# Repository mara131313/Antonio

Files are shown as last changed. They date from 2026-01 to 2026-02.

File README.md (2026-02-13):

# Antonio
Final project for "Introduction to Robotics" (2025–2026), focused on interactive robotics, audio-driven behavior, and custom human–robot interaction.  

Project by Andrei Cosmin Petru, Pincu Victor Andrei and Vraciu Mara Alina

## DESCRIPTION 
This project brings together two complementary builds into one cohesive system. There will be a robot moving on tank tracks and a touch screen remote that controls it.  

The robot is responsible for autonomous behavior, movement, and audio-visual feedback, while the remote provides an intuitive and playful human–robot interface.

### ABOUT ROBOT
The robot "ANTONIO" features a red panda–inspired designed for expressive and interactive behavior. ANTONIO will be equipped with a speaker capable of playing multiple music genres. For each music category, the robot will perform a specific “emote” by coordinating movements of its hands, head, tail, and “legs”, allowing it to dance according to the music.  

ANTONIO can move when the user interacts with a remote controller. If the user chooses to control the robot’s movement while it is dancing, they will have full control over its direction. Otherwise, ANTONIO will move autonomously based on the selected music genre.  

The remote includes an integrated microSD card on which music files can be downloaded and stored. Two music recognition methods are planned. The first method relies on manually assigned tags that define the genre of each song. The second method uses basic pattern recognition by analyzing drum rhythms, aiming to provide a lightweight and feasible genre classification approach. For this stage of our presentation, we implemented the first method.  
  
ANTONIO features two visual output elements:
- a face display used to show animated expressions
- a belly display that provides real-time audio visualization reacting to the rhythm and intensity of the music

#### 1. HANDS
  - wrists: 
    - up-down movement controlled by a servo motor and a gear mechanism
    - range is approximately 180°
  - shoulders: 
    - rotational movement driven by servo motors
    - range is up to 270°
2. HEAD:
  - neck: up-down movement controlled by a servo motor and a gear mechanism

3. TAIL: up-down movement controlled by a servo motor and a gear mechanism
  
4. LEGS: movement is achieved using tank tracks powered by DC motors
  - forward and backward motion : both tracks rotate at the same speed in the same direction
  - left and right turns: steering is performed using differential drive (one track moves while the other remains stationary)

### ABOUT REMOTE
The remote controller serves two main purposes: controlling the robot's movement and selecting various settings.  

The proposed design of the remote is inspired by a red panda paw, matching the robot’s red panda–inspired visual identity. This design was chosen to make the interaction playful, intuitive, and visually distinctive. At the center of the controller, a touch display will be integrated for menu navigation and visual feedback.  

An on/off power button will be placed on the tip of the pinky finger. The thumb fingertip will include a joystick used for controlling the robot's movement. Additionally, a buzzer will be integrated below the display, providing audio feedback when selecting or confirming menu options.  

1. MOVEMENT 
  - the robot's direction is controlled using a joystick located on the thumb
  - the joystick allows forward, backward, and left/right movement 
2. SETTINGS
  - remote settings:
    - theme song: allows turning the theme song on/off
    - volume: allows adjusting the volume of the buzzer
    - brightness: allows adjusting the brightness of the remote's display
  - music: allows selecting different tracks, skipping, pausing and selecting previous songs
  - robot settings:
    - face expression: allows changing ANTONIO's face from the established options
    - brightness: allows adjusting ANTONIO's 2 displays' brightness (*not yet*)
    - volume: allows adjusting ANTONIO'S spearks' volume (*not yet*)
    - speed: allows choosing the speed at which ANTONIO moves (*not yet*)
  - test mode: allows testing each moving component individually (*not yet*)
  - about creators: shows info about the creators of ANTONIO :
    - Vraciu Mara-Alina - https://github.com/mara131313
    - Andrei Cosmin Petru - https://github.com/cosmo1avo
    - Pincu Victor Andrei - https://github.com/PincuVictor  
    - each creator will have their own individual dance planned (*not yet*)

## BILL OF MATERIALS 
### ROBOT:
    - 4 x SG90 Servo motors
    - 2 x MG995 Servo motors
    - 2 x DC motors 125:1 Gear ratio
    - ESP32
    - Servo driver PCA9685
    - Charging module TP5100
    - Audio amplifier module PAM8403
    - 2 x Speaker 3W 4Ω
    - Microphone module
    - 2 x Samsung 18650 Li-ion 3.7V battery
    - Module slot card microSD
    - Module BMS Li-ion 2s 7.4V 20A
    - DC power jack adaptor
    - 2 x Voltage regulator buck converter LM2596
    - Dual H-bridge L298N
    - TFT/OLED display
    - OLED Display

### REMOTE:
    - Touch Display (NX4024K032_011)
    - ESP32 
    - 1 x Samsung 18650 Li-ion 3.7V battery
    - Charging module TP5100
    - Voltage regulator boost converter HW626
    - Buzzer
    - Capacitor
    - Joystick
    - Module BMS Li-ion 3.7V 20A
    - DC power jack adaptor

## Features
### ROBOT
- Audio-driven dancing behavior based on music genre
- Real-time audio playback from microSD card
- Music genre recognition system
- Expressive animated face display
- Real-time audio-reactive belly visualization
- Coordinated multi-servo movement (hands, head, tail)
- Differential drive tank-track locomotion
- Autonomous movement based on selected music genre
- Manual movement override via remote controller
- Modular and expandable hardware architecture

### REMOTE
- Touchscreen: multi-page menu system with smooth scrolling for the music library.
- Joystick-based movement control
- Audio Feedback: buzzer calibrated for musical frequencies and variable volume using PWM (Duty Cycle) mapping
- Visual feedback through touch display
- Wireless Communication: real-time transmission using the ESP-NOW protocol to ensure minimal latency

### SYSTEM
- Concurrent handling of motors, audio, and displays
- Real-time human–robot interaction

## QUESTIONS
### 1. What is the system boundary?
For the robot:
  - inside: ESP32, all motors, OLEDs, Audio (Speaker, Amp), Battery and physical chassis/tracks.
  - outside: the floor, obstacles and the bluetooth signal from the remote.

For the remote:
  - inside: ESP32, Touchscreen, joystick, push button and an internal battery.
  - outside: the user (human) and the bluetooth signal being sent to the robot.

### 2. Where does intelligence live?
Primary intelligence lives in the robot, which processes input from the remote and makes decisions related to movement, audio playback, and visual feedback.

### 3. What is the hardest technical problem?
The hardest technical problem will be system concurrency. Having a lot of motors, audio and updating the display  will make synchronization more difficult, therefore creating blocking problems if not handled properly. 

### 4. What is the minimum demo?

The minimum demo will be showing moving on tank tracks. The movement is controlled by the touchscreen remote. Ideally, in this prototype we will be able to play at least one track on the speaker and react to it.

### 5. Why is this not just a tutorial?
This is not just a tutorial because we are making our own designs for the robot's design and movement, our own interface for the remote, and our own unique interactions. This tutorial would have to include days worth of footage to cover the steps.

### 6. Do you need an ESP32?
 Yes, we will be needing 2 ESP32.

## ROUGH SKETCH
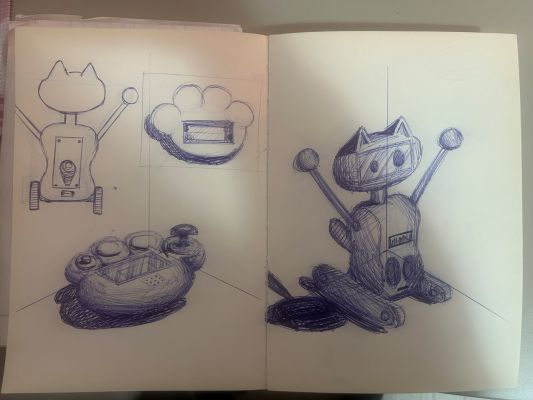
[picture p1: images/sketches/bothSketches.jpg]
Sketch


## IMPLEMENTATION DETAILS
This section outlines the realization of the project, transitioning from initial concepts to the fully functional physical prototype.

### 3D DESIGN & MODELING
The physical structure of both ANTONIO and the remote was modeled from scratch to adhere to the Red Panda aesthetic while ensuring mechanical robustness.
- **Robot Chassis, Arms, and Head:** Engineered to house dual Li-ion batteries, speakers, the visualizer screen, ESP32, H-bridge motor driver, breadboards, shift registers, amplifier, microphone, and DC motors (driving the master/slave wheels and tracks). The design integrates a charging module, BMS, voltage regulators, and a 3.5-inch display, while providing sturdy anchor points for the 6 servos controlling the arms, head, tail, and paws.
- **Locomotion System:** Custom-designed sprocket wheels and track links, 3D printed to ensure optimal grip and smooth differential steering.
- **Remote Casing:** Modeled as a stylized paw, prioritizing ergonomics for joystick manipulation and touchscreen visibility. The enclosure accommodates a Li-ion battery, ESP32, switch button, touchscreen (with stylus), charging module, BMS, buzzer, voltage regulator, and microSD card slot.
- **Lead Designer:** **Andrei Cosmin-Petru** is responsible for designing and modeling all custom 3D components for the project.

### REMOTE INTERFACE (GUI)
The remote serves as the command center, featuring a custom Graphical User Interface (GUI) tailored for the touch display.
- **Menu Structure:** Organized into intuitive pages (Test Mode, Settings, Music) with large, touch-friendly elements. It includes configuration settings for both ANTONIO and the remote, enabling customizations such as facial expressions, theme songs, brightness and description of the project's creators. The music tab features a scrollable list of 20 songs, displays random custom artwork for each track, and includes playback controls (pause/resume, next, previous).
- **User Feedback:** Provides immediate visual updates on the screen and audio cues via the integrated buzzer when commands are registered.
- **Data Transmission:** Encodes user inputs (drive vectors, volume states, emote requests) into optimized data packets sent wirelessly to the robot.
- **Lead Developer (Interface):** **Vraciu Mara Alina** is responsible for designing and implementing the custom, intuitive user interface, with each component across every page individually crafted and built from the ground up.

### FIRMWARE & CONTROL LOGIC
The "brain" of the robot is designed to handle high-concurrency requirements, ensuring that music playback remains uninterrupted while the robot dances or moves.
- **Dual-Core Architecture:** Leverages the ESP32's dual cores to separate blocking tasks (Audio decoding, WiFi/ESP-NOW communication on Core 0) from real-time operations (Motor control, Servo choreography, Display updates on Core 1).
- **Audio-Motion Synchronization:** Utilizes specific algorithms to translate music genres into distinct servo choreographies.
- **State Management:** Implements a robust state machine that seamlessly switches between "Autonomous Dance Mode" and "Manual Override" instantly upon detecting joystick input.
- **Lead Developer:** **Pincu Victor Andrei** is responsible for component selection and the electrical design strategy, ensuring optimal power distribution and operational safety. He also developed the hardware logic and communication between modules using FreeRTOS.

### ASSEMBLY & INTEGRATION
The final build focused on reliable power distribution and the compact integration of all components.
- **Power Management:** Integration of BMS modules and buck converters to supply stable, isolated voltage levels for the logic units (3.3V/5V) and high-torque motors (7.4V).
- **Wire Routing:** Strategic internal cable management to prevent interference with moving parts, particularly around the rotating shoulder and neck mechanisms.
- **Component Mounting:** Secure placement of the PCA9685 driver and L298N motor controller to ensure vibration resistance and effective heat dissipation.
- **Assembly Team:** All three creators are responsible for the physical assembly of the project, including soldering, surface finishing (sanding), component placement, and final system integration.

## DIAGRAMS
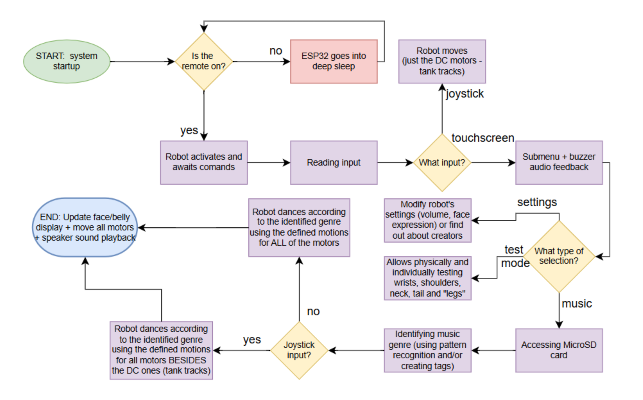
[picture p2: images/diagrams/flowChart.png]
SoftwareArchitecture


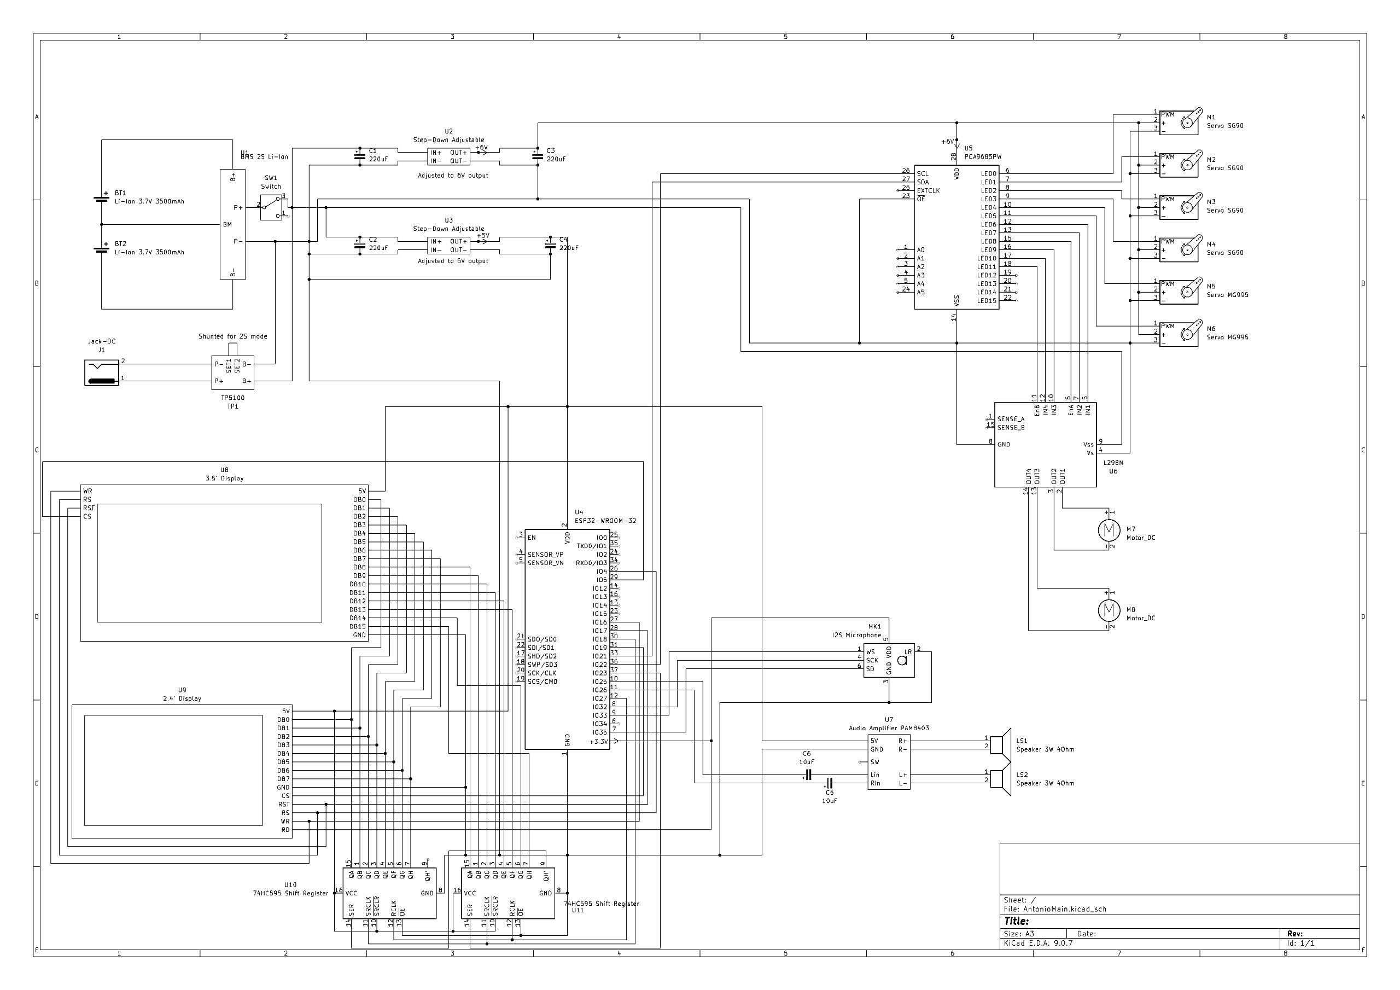
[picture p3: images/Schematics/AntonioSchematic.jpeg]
AntonioSchematic


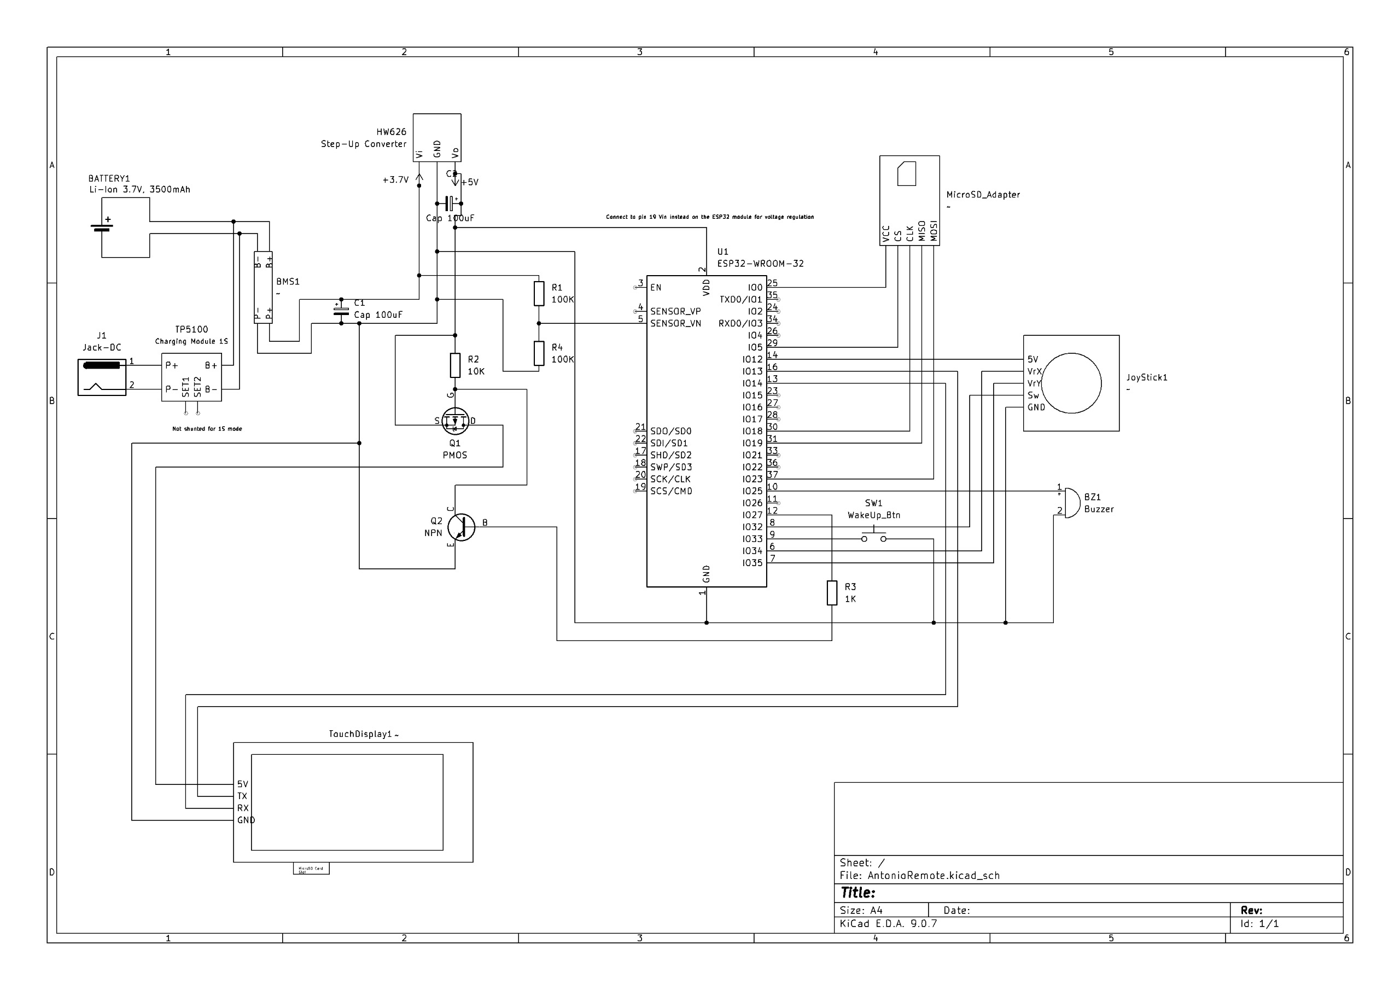
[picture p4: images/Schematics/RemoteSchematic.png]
RemoteChematic


- Link to the youtube video:
https://youtu.be/va7jiXDgWas

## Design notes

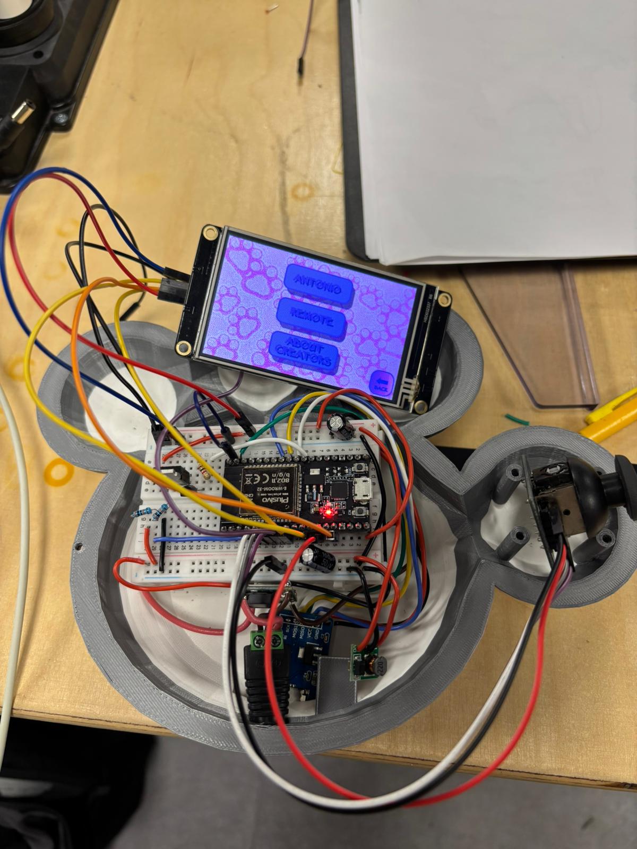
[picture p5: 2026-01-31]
images/ProgressPhotosRemote/Progress4.jpeg

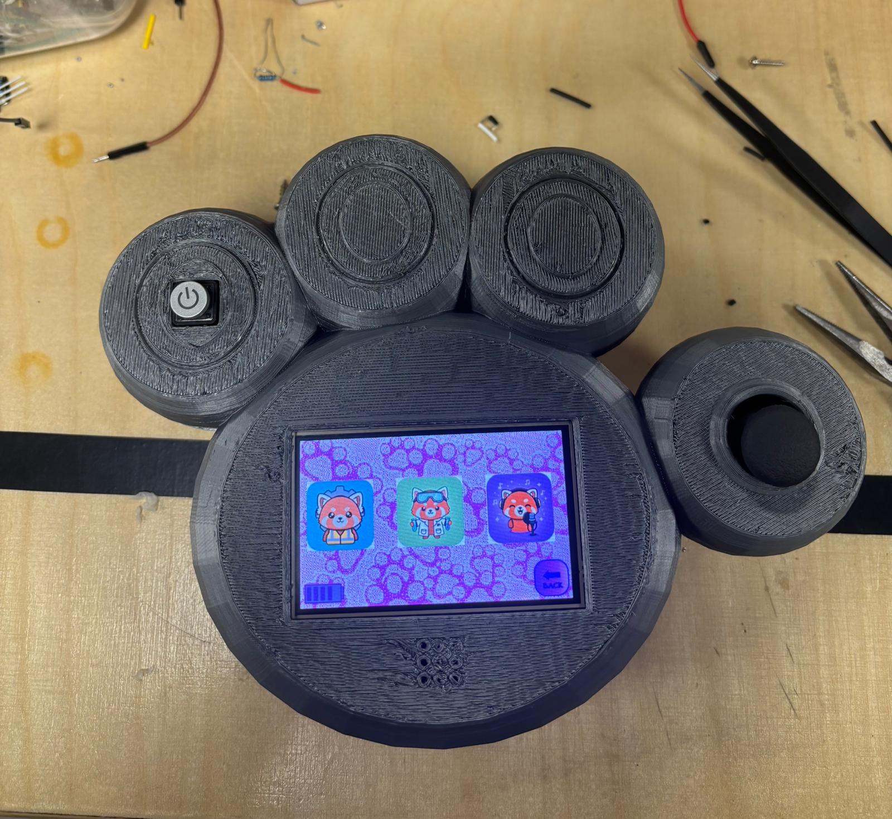
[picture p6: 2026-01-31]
images/ProgressPhotosRemote/Progress8.jpeg

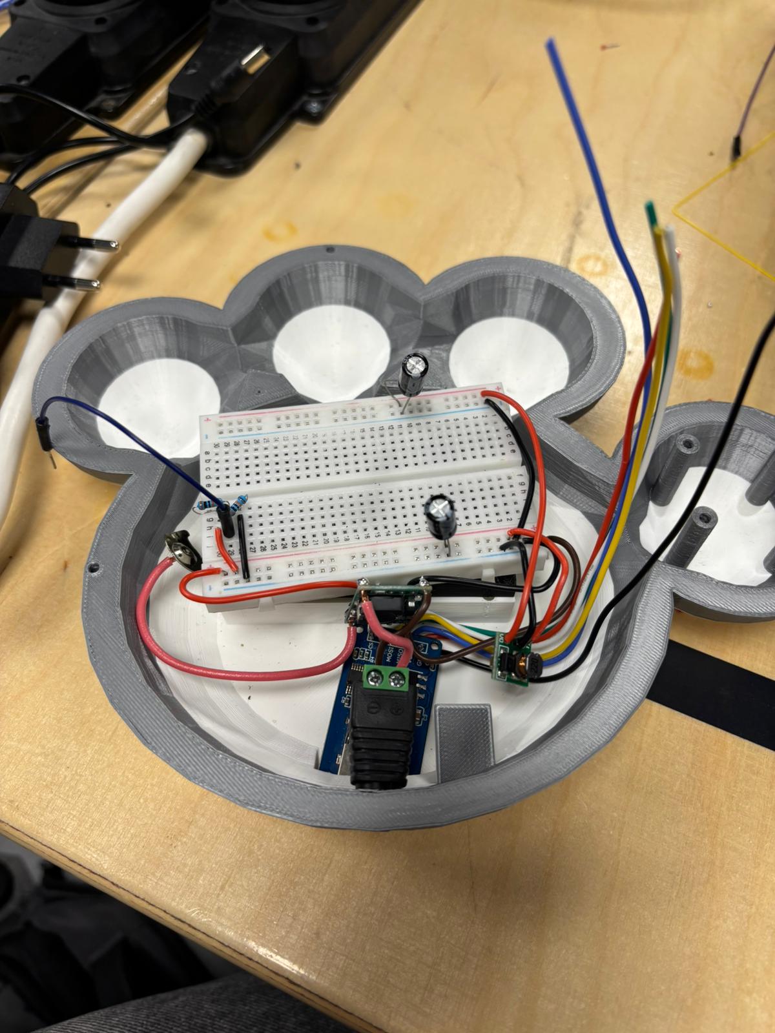
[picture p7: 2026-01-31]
images/ProgressPhotosRemote/Progress3.jpeg

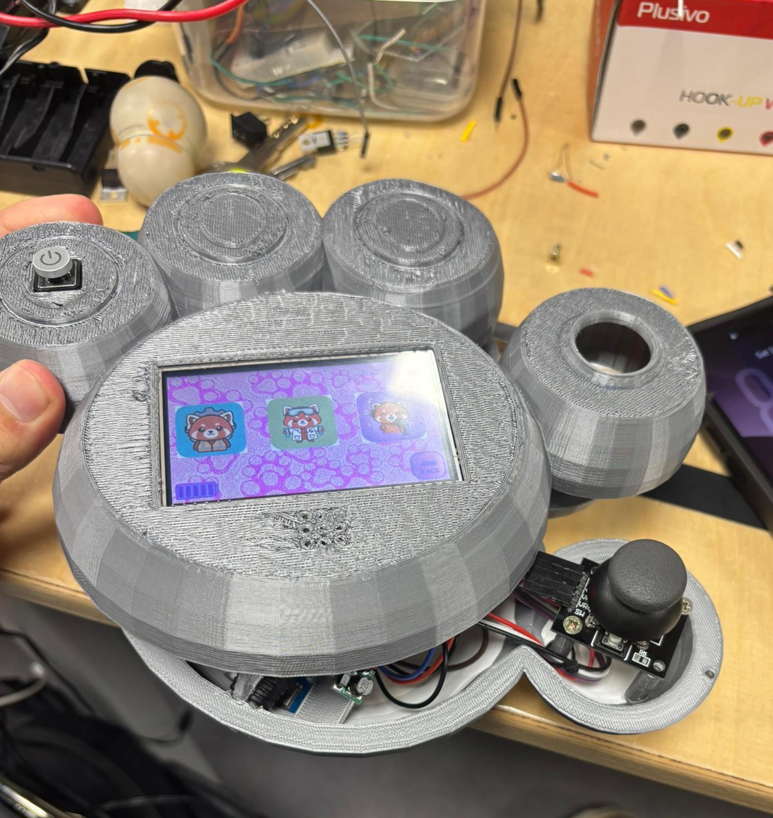
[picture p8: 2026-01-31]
images/ProgressPhotosRemote/Progress7.jpeg

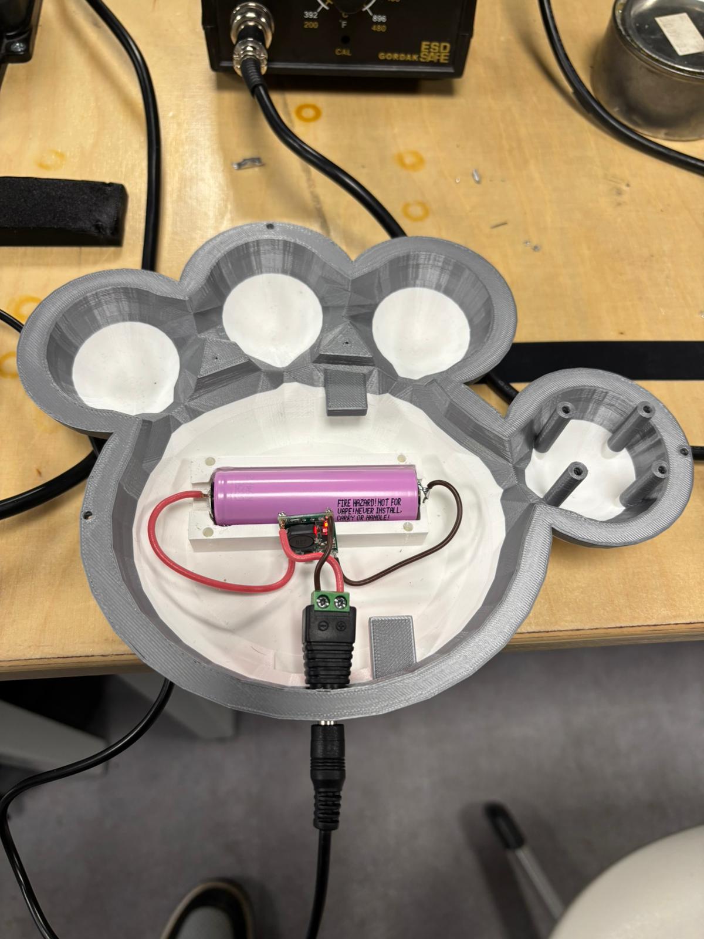
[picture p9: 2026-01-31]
images/ProgressPhotosRemote/Progress2.jpeg

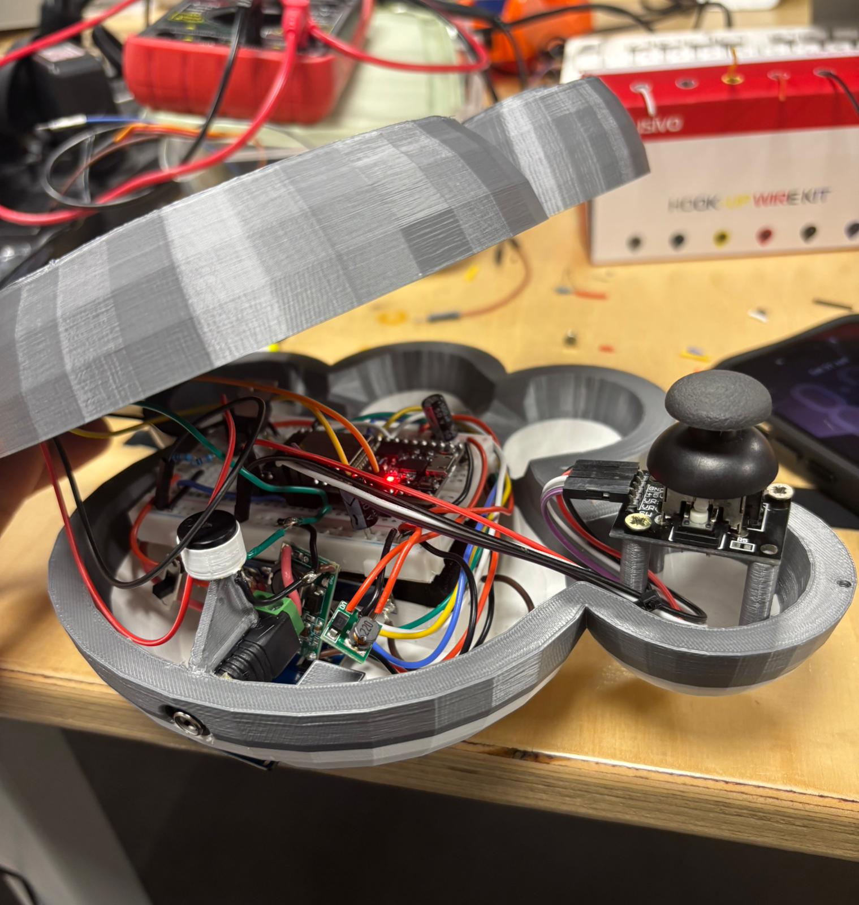
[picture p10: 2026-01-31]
images/ProgressPhotosRemote/Progress6.jpeg

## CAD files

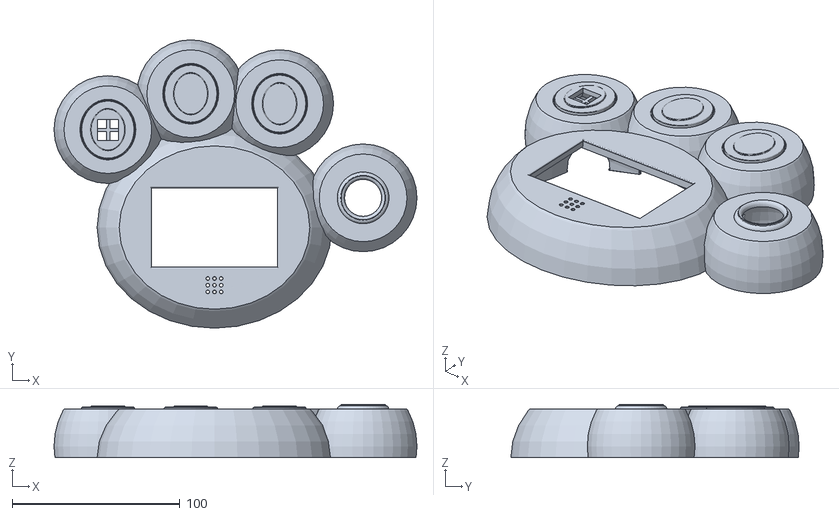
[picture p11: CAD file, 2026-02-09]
others/Stl Files/remoteup.stl
216.4 x 171.9 x 31.9

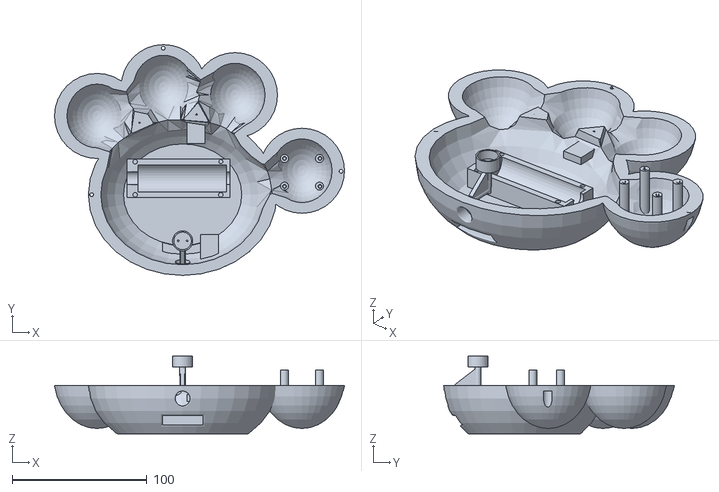
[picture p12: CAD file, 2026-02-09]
others/Stl Files/remotedown.stl
215.3 x 171.4 x 57.7

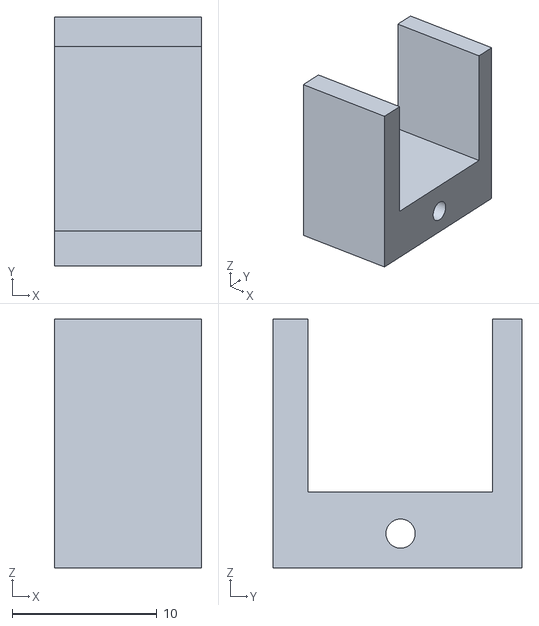
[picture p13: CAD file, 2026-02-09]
others/Stl Files/servo tail holder test.stl
10.2 x 17.2 x 17.2

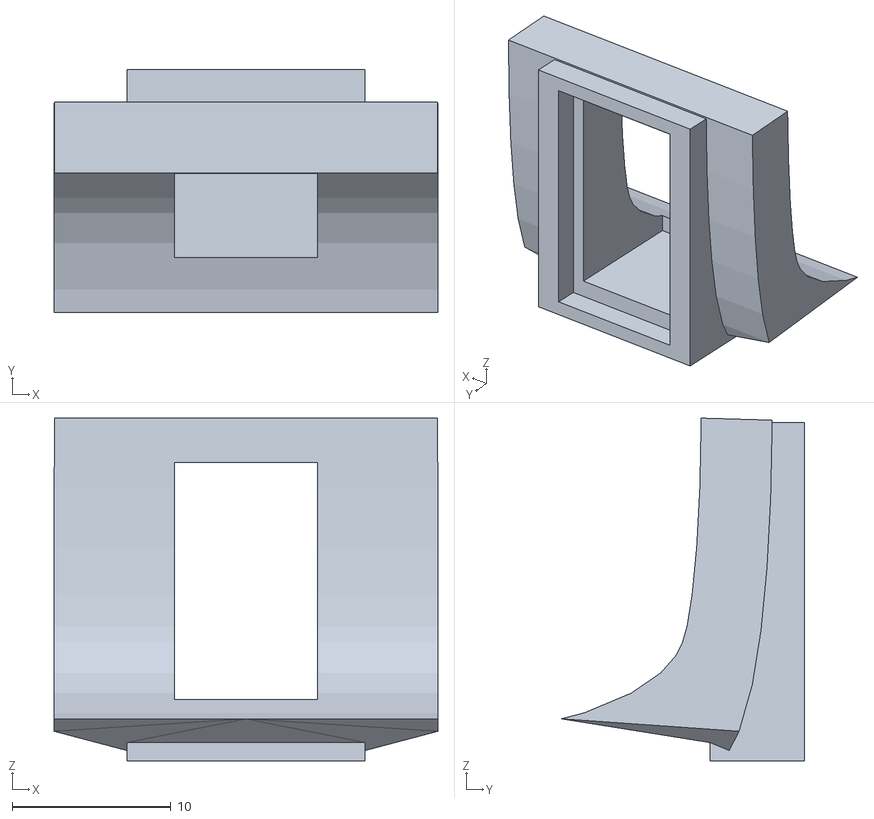
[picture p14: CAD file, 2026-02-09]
others/Stl Files/button test.stl
24.2 x 15.3 x 21.6

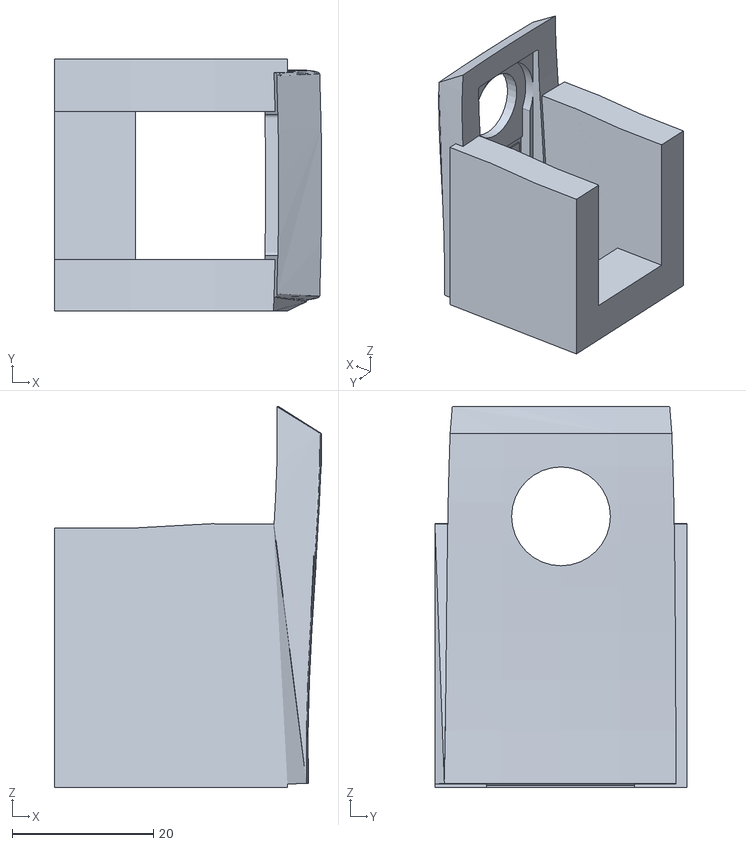
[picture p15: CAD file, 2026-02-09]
others/Stl Files/servo arm holder test.stl
37.9 x 35.7 x 54.0

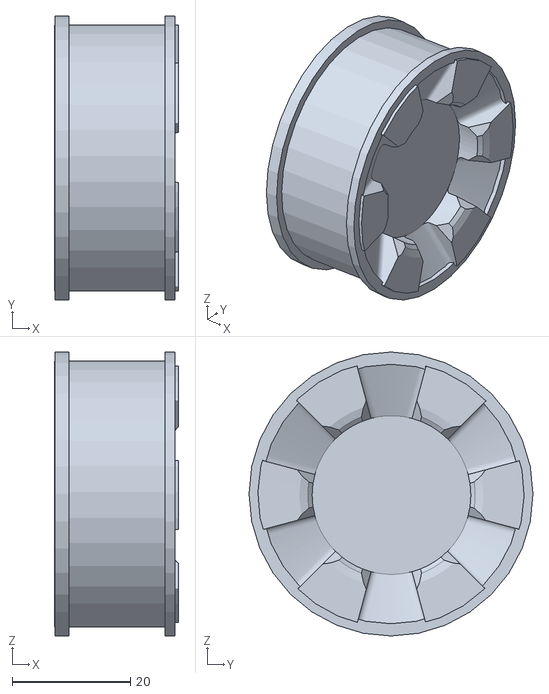
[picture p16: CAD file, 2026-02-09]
others/Stl Files/slave wheel test.stl
21.0 x 48.0 x 48.0

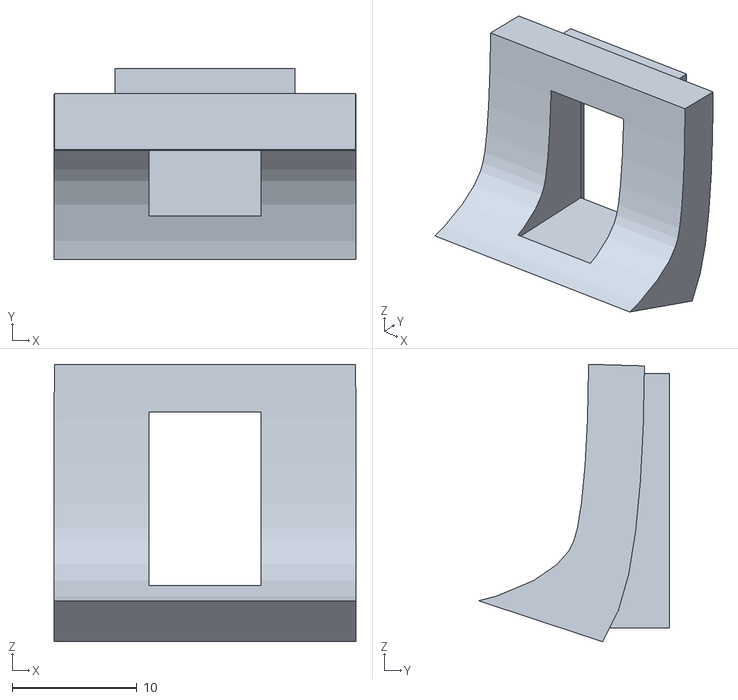
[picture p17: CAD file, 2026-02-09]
others/Stl Files/button holder test.stl
24.2 x 15.3 x 22.2

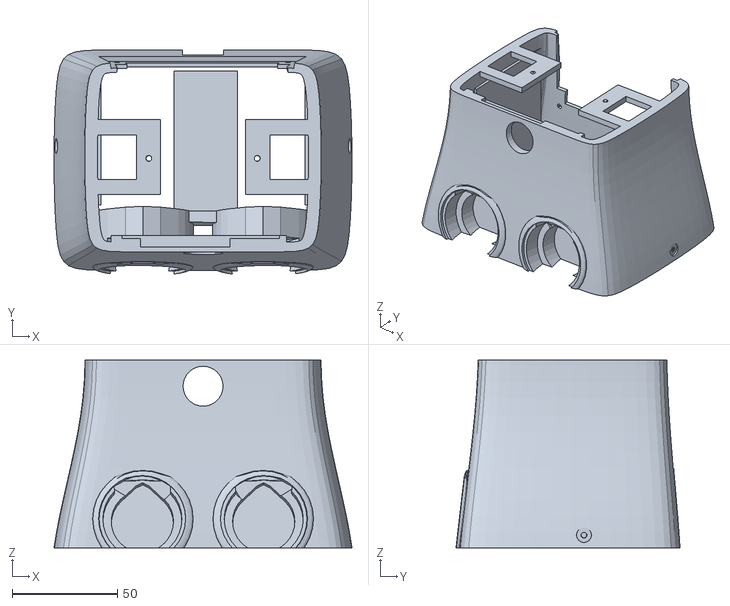
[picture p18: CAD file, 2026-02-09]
others/Stl Files/body mid.stl
141.7 x 106.5 x 89.4

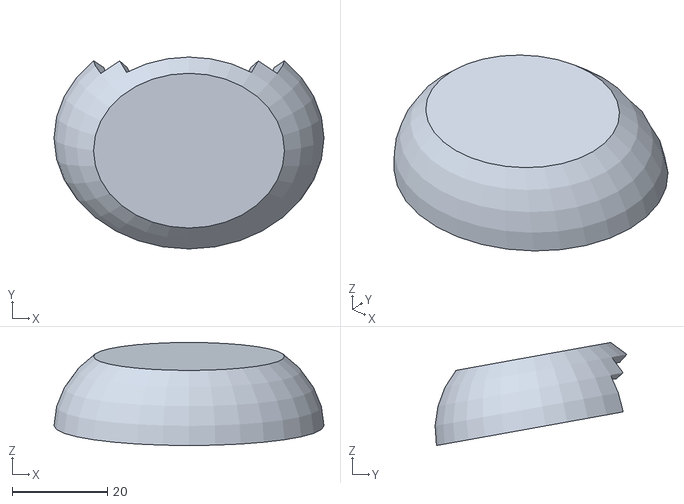
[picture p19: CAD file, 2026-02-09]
others/Stl Files/paw up left.stl
56.6 x 40.2 x 21.6

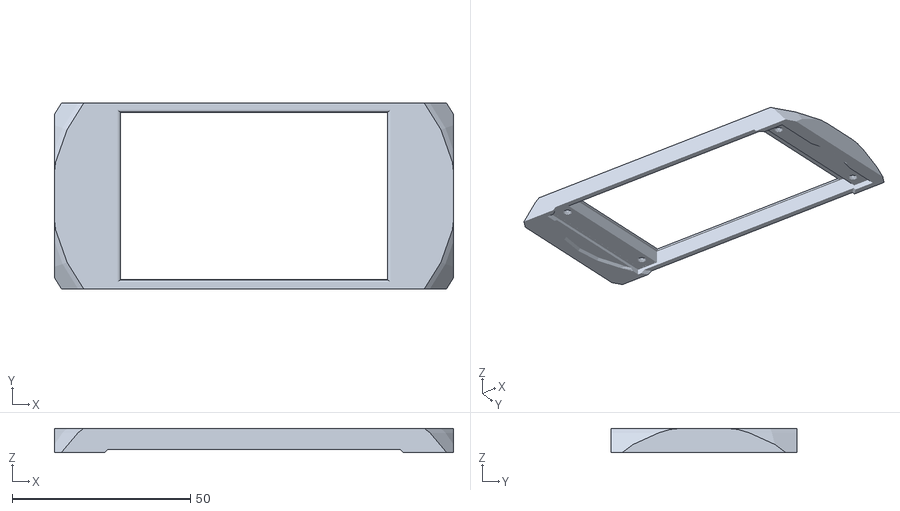
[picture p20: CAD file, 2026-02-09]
others/Stl Files/touchscreen test.stl
112.1 x 52.1 x 6.75

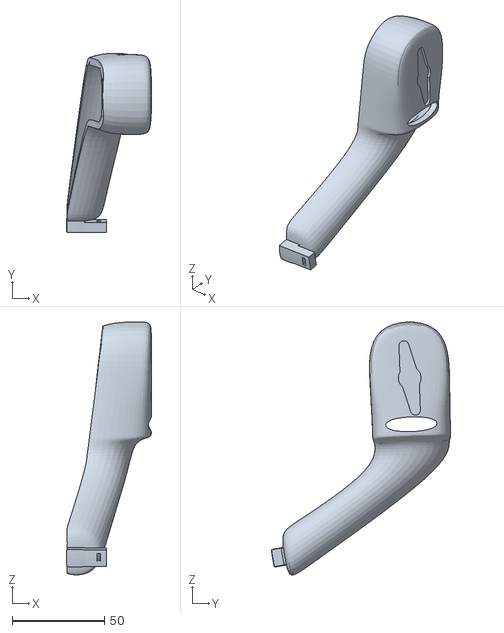
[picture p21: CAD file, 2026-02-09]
others/Stl Files/arm left int.stl
46.2 x 97.4 x 137.3

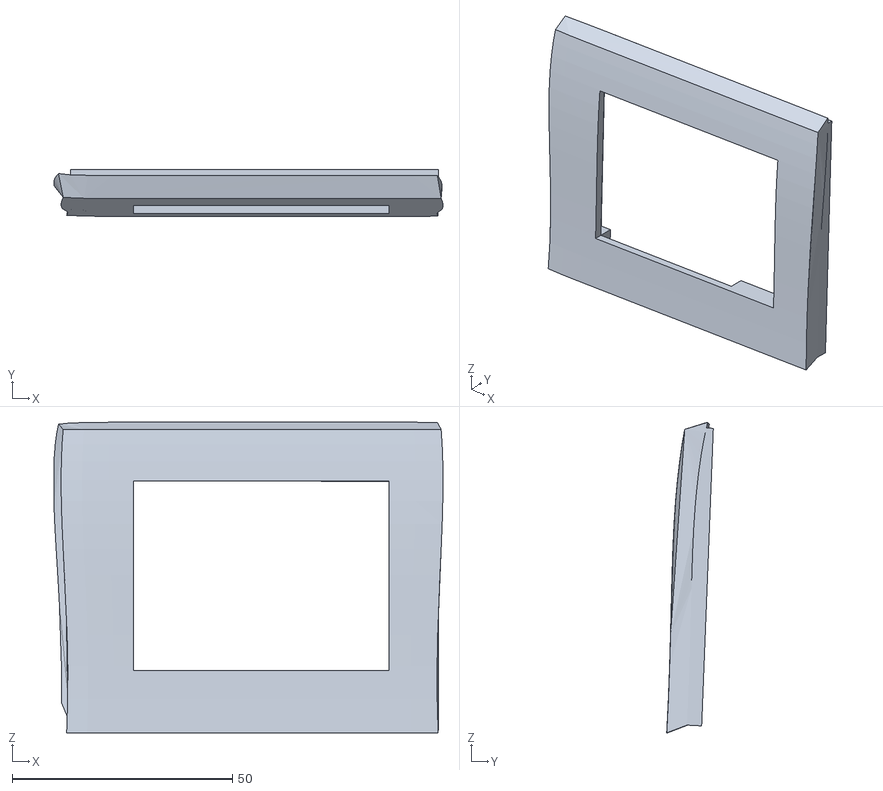
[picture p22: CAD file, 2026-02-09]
others/Stl Files/soundwave test.stl
88.2 x 10.6 x 70.4

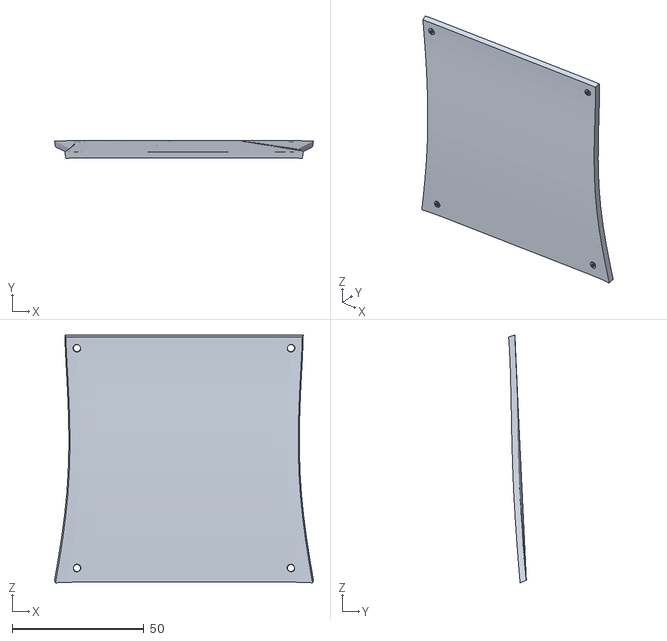
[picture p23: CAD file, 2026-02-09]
others/Stl Files/cap.stl
98.4 x 6.76 x 94.1

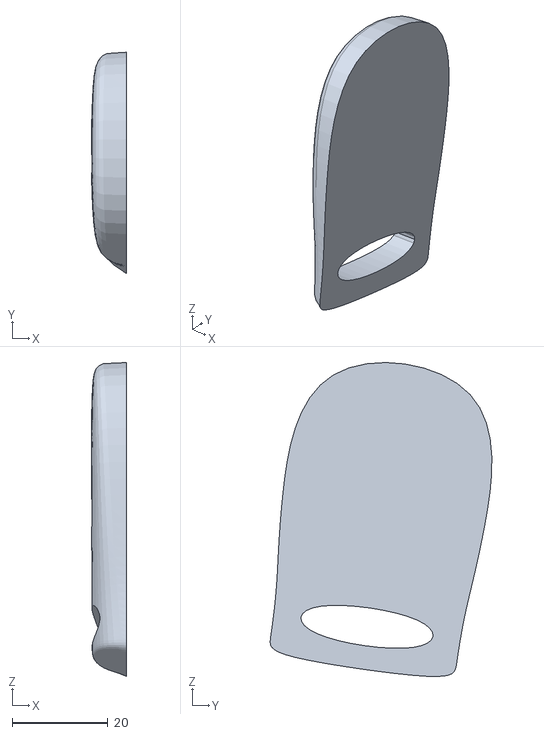
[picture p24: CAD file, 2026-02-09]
others/Stl Files/armpit test.stl
7.34 x 46.2 x 65.5

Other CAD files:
others/Stl Files/paw up right.stl
others/Stl Files/motor tension test.stl
others/Stl Files/slave connect.stl
others/Stl Files/button cap.stl
others/Stl Files/arm left ext.stl
others/Stl Files/arm right ext.stl
others/Stl Files/arm right int.stl
others/Stl Files/bat down test.stl
others/Stl Files/bat up test.stl
others/Stl Files/body high.stl
others/Stl Files/body low.stl
others/Stl Files/bolt.stl
others/Stl Files/cap test1.stl
others/Stl Files/cap test2.stl
others/Stl Files/head down.stl
others/Stl Files/head screen test.stl
others/Stl Files/head up.stl
others/Stl Files/master wheel test.stl
others/Stl Files/master wheel.stl
others/Stl Files/mic test.stl
others/Stl Files/paw down left.stl
others/Stl Files/paw down right.stl
others/Stl Files/paw extension test.stl
others/Stl Files/paw servo test.stl
others/Stl Files/speaker rim test.stl
others/Stl Files/tail test.stl
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

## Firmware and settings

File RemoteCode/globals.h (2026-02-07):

#ifndef GLOBALS_H
#define GLOBALS_H

#define JOYSTICK_X_PIN 34
#define JOYSTICK_Y_PIN 35
#define JOYSTICK_SW_PIN 32
#define PUSH_BUTTON_PIN GPIO_NUM_33
#define BUZZER_PIN 25
#define BATTERY_PIN 39
#define DISPLAY_POWER_PIN 17

#define RXD2 13
#define TXD2 14

#define BAUD_RATE 115200
#define NEXTION_BAUD 9600
#define SLEEP_THRESHOLD 2000

//IDs for the battery images
#define BATT_ICON_0_PERCENT 37
#define BATT_ICON_25_PERCENT 38
#define BATT_ICON_50_PERCENT 39
#define BATT_ICON_75_PERCENT 40
#define BATT_ICON_100_PERCENT 41

//IDs for individual song images
#define SONG_0 59
#define SONG_1 60
#define SONG_2 61
#define SONG_3 62
#define SONG_4 63
#define SONG_5 64

#define MAX_SONGS 20
#define MAX_NAME_LEN 64

//toggle buttons
#define SONG_PLAY 16
#define SONG_PAUSE 15
#define TEST_PLAY_ON 34
#define TEST_PLAY_OFF 33
#define TEST_STOP_ON 36
#define TEST_STOP_OFF 35
#define THEME_OFF 11
#define THEME_ON 10
#define HAPPY_OFF 51
#define HAPPY_ON 52
#define PLAYFUL_OFF 53
#define PLAYFUL_ON 54
#define HEART_OFF 55
#define HEART_ON 56
#define DEFAULT_OFF 57 
#define DEFAULT_ON 58
#define FAST_ON 1
#define FAST_OFF 2
#define MED_ON 4
#define MED_OFF 3
#define SLOW_OFF 5
#define SLOW_ON 6

// for sending protocols
#define EVENT_SEND_REMOTE_STATE  (1 << 0)
#define EVENT_SEND_STREAMING     (1 << 1)

//for the theme song
#define NOTE_C4  262
#define NOTE_E4  330
#define NOTE_G4  392
#define NOTE_C5  523
#define NOTE_A4  440

// GENRE DEFINITIONS
enum MusicGenre {
    GENRE_DEFAULT = 0,
    GENRE_POP = 1,
    GENRE_RAP = 2,
    GENRE_ROC = 3,
    GENRE_MAN = 4,
    GENRE_EDM = 5
};

struct DriveCommand {
    int8_t drive;
    int8_t steer;
};

struct RemoteState {
    DriveCommand dc;
    uint8_t volume;
    uint8_t brightness;
    uint8_t faceIdx;
    uint8_t speed;
    uint8_t testPart;
    bool isTesting;
    bool isSwPressed;
    bool musicPlaying;
    uint8_t trackID;
    uint8_t currentGenre;
};

struct StreamingPacket{
    uint32_t packetId;
    uint8_t audioData[240];
    uint8_t driveControl;
    DriveCommand dc;
};

void triggerBeep(int freq = 2000, int duration = 50);

extern EventGroupHandle_t commsEvents;
extern StreamingPacket myStreaming;
extern uint8_t songGenres[MAX_SONGS];

#endif

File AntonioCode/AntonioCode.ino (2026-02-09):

#include <esp_now.h>
#include <WiFi.h>
#include <esp_wifi.h>
#include <freertos/stream_buffer.h>
#include <freertos/queue.h>
#include <driver/dac_oneshot.h>
#include <SPI.h>
#include <Wire.h>
#include <Adafruit_PWMServoDriver.h>

// ========================================
//  PINI HARDWARE
// ========================================
#define TFT_WR   17
#define TFT_RS   4
#define TFT_RST  16
#define SR_LATCH 27

#define TFT_CS_SMALL 19
#define TFT_CS_BIG   5

// I2C Pinii
#define I2C_SDA 21
#define I2C_SCL 22

// ========================================
//  CONFIGURARE MOTOARE
// ========================================
#define MOTOR1_IN1 7   
#define MOTOR1_IN2 8   
#define MOTOR1_ENA 9   

#define MOTOR2_IN3 10  
#define MOTOR2_IN4 11  
#define MOTOR2_ENB 12  

#define VITEZA_MAX 4095

Adafruit_PWMServoDriver pwm = Adafruit_PWMServoDriver(0x40);
SPIClass spi(VSPI);

// ========================================
//  STRUCTURI DATE & COZI
// ========================================
struct DriveCommand {
    int8_t drive; 
    int8_t steer; 
};

struct MotorPacket {
    int8_t drive;
    int8_t steer;
    uint8_t speed;
};

struct RemoteState {
    DriveCommand dc;
    uint8_t volume;
    uint8_t brightness;
    uint8_t faceIdx;
    uint8_t speed;
    uint8_t testPart;
    bool isTesting;
    bool isSwPressed;
    bool musicPlaying;
    uint8_t trackID;
    uint8_t currentGenre;
};

struct StreamingPacket {
    uint32_t packetId;
    uint8_t audioData[240];
    uint8_t driveControl;
    DriveCommand dc;
};

// Globale
RemoteState incomingDataState;
StreamingPacket incomingDataSP;
StreamBufferHandle_t audioBuffer;
QueueHandle_t motorQueue;
dac_oneshot_handle_t dac_left, dac_right;
esp_timer_handle_t audio_timer;

// Display
#define SMALL_W 320
#define SMALL_H 240
#define BIG_W   480
#define BIG_H   320

#define COLOR_BLACK   0x0000
#define COLOR_BG      0x0000 
#define COLOR_WHITE   0xFFFF
#define COLOR_RED     0xF800
#define COLOR_GREEN   0x07E0
#define COLOR_BLUE    0x001F
#define COLOR_YELLOW  0xFFE0
#define COLOR_CYAN    0x07FF
#define COLOR_MAGENTA 0xF81F
#define COLOR_BASS    0xF800
#define COLOR_MID     0x07E0
#define COLOR_HIGH    0x001F

#define NUM_BANDS 16
#define BAND_WIDTH (SMALL_W / NUM_BANDS)
#define BAND_SPACING 2
#define BAR_Y_OFFSET 20
#define MAX_BAR_HEIGHT (SMALL_H - 40)

uint8_t bandLevels[NUM_BANDS] = {0};
uint8_t prevBandLevels[NUM_BANDS] = {0};
bool strobeActive = false;
unsigned long strobeStartTime = 0;
bool screenIsBlack = true;
int bassThreshold = 95;

volatile int currentVolume = 0;
volatile unsigned long lastRecvTime = 0;
volatile uint8_t activeGenre = 0;
bool musicPlaying = false;
uint8_t currentFace = 255;

// ========================================
//  DRIVER ECRAN
// ========================================
void writeBus8_Small(uint8_t data) {
    spi.write(0x00); spi.write(data);
    digitalWrite(SR_LATCH, LOW); digitalWrite(SR_LATCH, HIGH);
}
void writeBus16_Big(uint16_t data) {
    spi.write(data >> 8); spi.write(data & 0xFF);
    digitalWrite(SR_LATCH, LOW); digitalWrite(SR_LATCH, HIGH);
}
void cmdSmall(uint8_t cmd) {
    digitalWrite(TFT_CS_BIG, HIGH); digitalWrite(TFT_CS_SMALL, LOW);
    digitalWrite(TFT_RS, LOW); digitalWrite(TFT_WR, LOW);
    writeBus8_Small(cmd);
    digitalWrite(TFT_WR, HIGH); digitalWrite(TFT_CS_SMALL, HIGH);
}
void dataSmall(uint8_t data) {
    digitalWrite(TFT_CS_BIG, HIGH); digitalWrite(TFT_CS_SMALL, LOW);
    digitalWrite(TFT_RS, HIGH); digitalWrite(TFT_WR, LOW);
    writeBus8_Small(data);
    digitalWrite(TFT_WR, HIGH); digitalWrite(TFT_CS_SMALL, HIGH);
}
void data16Small(uint16_t data) {
    digitalWrite(TFT_CS_BIG, HIGH); digitalWrite(TFT_CS_SMALL, LOW);
    digitalWrite(TFT_RS, HIGH);
    digitalWrite(TFT_WR, LOW); writeBus8_Small(data >> 8);   digitalWrite(TFT_WR, HIGH);
    digitalWrite(TFT_WR, LOW); writeBus8_Small(data & 0xFF); digitalWrite(TFT_WR, HIGH);
    digitalWrite(TFT_CS_SMALL, HIGH);
}
void setAddrWindowSmall(uint16_t x0, uint16_t y0, uint16_t x1, uint16_t y1) {
    cmdSmall(0x2A); data16Small(x0); data16Small(x1);
    cmdSmall(0x2B); data16Small(y0); data16Small(y1);
    cmdSmall(0x2C);
}
void fillRectSmall(uint16_t x, uint16_t y, uint16_t w, uint16_t h, uint16_t color) {
    if (w == 0 || h == 0) return;
    setAddrWindowSmall(x, y, x + w - 1, y + h - 1);
    uint32_t pixels = (uint32_t)w * h;
    digitalWrite(TFT_CS_BIG, HIGH); digitalWrite(TFT_CS_SMALL, LOW); digitalWrite(TFT_RS, HIGH);
    for (uint32_t i = 0; i < pixels; i++) {
        digitalWrite(TFT_WR, LOW); spi.write(0x00); spi.write(color >> 8);
        digitalWrite(SR_LATCH, LOW); digitalWrite(SR_LATCH, HIGH); digitalWrite(TFT_WR, HIGH);
        digitalWrite(TFT_WR, LOW); spi.write(0x00); spi.write(color & 0xFF);
        digitalWrite(SR_LATCH, LOW); digitalWrite(SR_LATCH, HIGH); digitalWrite(TFT_WR, HIGH);
    }
    digitalWrite(TFT_CS_SMALL, HIGH);
}
void clearSmall(uint16_t color) { fillRectSmall(0, 0, SMALL_W, SMALL_H, color); }
void triggerStrobe(bool active) { cmdSmall(active ? 0x21 : 0x20); }

void cmdBig(uint8_t cmd) {
    digitalWrite(TFT_CS_SMALL, HIGH); digitalWrite(TFT_CS_BIG, LOW);
    digitalWrite(TFT_RS, LOW); digitalWrite(TFT_WR, LOW);
    writeBus16_Big((uint16_t)cmd);
    digitalWrite(TFT_WR, HIGH); digitalWrite(TFT_CS_BIG, HIGH);
}
void dataBig(uint16_t data) {
    digitalWrite(TFT_CS_SMALL, HIGH); digitalWrite(TFT_CS_BIG, LOW);
    digitalWrite(TFT_RS, HIGH); digitalWrite(TFT_WR, LOW);
    writeBus16_Big(data);
    digitalWrite(TFT_WR, HIGH); digitalWrite(TFT_CS_BIG, HIGH);
}
void setAddrWindowBig(uint16_t x0, uint16_t y0, uint16_t x1, uint16_t y1) {
    cmdBig(0x2A); dataBig(x0 >> 8); dataBig(x0 & 0xFF); dataBig(x1 >> 8); dataBig(x1 & 0xFF);
    cmdBig(0x2B); dataBig(y0 >> 8); dataBig(y0 & 0xFF); dataBig(y1 >> 8); dataBig(y1 & 0xFF);
    cmdBig(0x2C);
}
void fillRectBig(uint16_t x, uint16_t y, uint16_t w, uint16_t h, uint16_t color) {
    if (w == 0 || h == 0) return;
    setAddrWindowBig(x, y, x + w - 1, y + h - 1);
    uint32_t pixels = (uint32_t)w * h;
    digitalWrite(TFT_CS_SMALL, HIGH); digitalWrite(TFT_CS_BIG, LOW); digitalWrite(TFT_RS, HIGH);
    for (uint32_t i = 0; i < pixels; i++) {
        digitalWrite(TFT_WR, LOW); writeBus16_Big(color); digitalWrite(TFT_WR, HIGH);
    }
    digitalWrite(TFT_CS_BIG, HIGH);
}
void clearBig(uint16_t color) { fillRectBig(0, 0, BIG_W, BIG_H, color); }
void drawFace(uint8_t faceIdx) {
    uint16_t bg = COLOR_BLACK; uint16_t eyeColor = COLOR_WHITE;
    switch (faceIdx) {
        case 1: bg = COLOR_YELLOW; eyeColor = COLOR_BLACK; break;
        case 2: bg = COLOR_CYAN; eyeColor = COLOR_BLACK; break;
        case 3: bg = 0xF81F; eyeColor = COLOR_WHITE; break;
        default: bg = COLOR_BLACK; eyeColor = COLOR_GREEN; break;
    }
    clearBig(bg);
    int eyeSize = 60; int eyeY = 100;
    fillRectBig(100, eyeY, eyeSize, eyeSize, (faceIdx == 3) ? COLOR_RED : eyeColor);
    fillRectBig(320, eyeY, eyeSize, eyeSize, (faceIdx == 3) ? COLOR_RED : eyeColor);
    if (faceIdx == 1) {
        fillRectBig(140, 240, 200, 30, eyeColor); fillRectBig(140, 240, 30, 60, eyeColor); fillRectBig(310, 240, 30, 60, eyeColor);
    } else if (faceIdx == 3) {
        fillRectBig(160, 220, 160, 20, COLOR_RED);
    } else {
        fillRectBig(140, 240, 200, 20, eyeColor);
    }
    cmdBig(0x00); digitalWrite(TFT_CS_BIG, HIGH);
}

uint16_t getGradientColor(uint8_t level, uint8_t bandIndex) {
    if (bandIndex < 6) return COLOR_BASS;
    else if (bandIndex < 12) return COLOR_MID;
    else return COLOR_HIGH;
}

void updateVisualizerFromAudio() {
    static float phase = 0;
    if (currentVolume > bassThreshold && !strobeActive) {
        triggerStrobe(true); strobeActive = true; strobeStartTime = millis();
        bandLevels[0] = 255; bandLevels[1] = 240;
    }
    if (strobeActive && (millis() - strobeStartTime > 35)) {
        triggerStrobe(false); strobeActive = false;
    }
    float volumeFactor = currentVolume / 60.0;
    if (volumeFactor > 2.5) volumeFactor = 2.5;
    for (int i = 2; i < NUM_BANDS; i++) {
        int wave = 50 + 40 * sin(phase * (i * 0.3) + millis() / 150.0);
        int finalVal = wave * volumeFactor; finalVal += random(-5, 5);
        bandLevels[i] = constrain(finalVal, 0, 255);
    }
    if (!strobeActive) {
        if (bandLevels[0] > 0) bandLevels[0] -= 20;
        if (bandLevels[1] > 0) bandLevels[1] -= 15;
        if (bandLevels[0] < currentVolume * 2) bandLevels[0] = currentVolume * 2;
    }
    phase += 0.2;
    for (int i = 0; i < NUM_BANDS; i++) {
        uint8_t currentLevel = bandLevels[i]; uint8_t prevLevel = prevBandLevels[i];
        if (abs(currentLevel - prevLevel) < 3) continue;
        uint16_t x = i * BAND_WIDTH + BAND_SPACING; uint16_t barWidth = BAND_WIDTH - (2 * BAND_SPACING);
        uint16_t currentHeight = map(currentLevel, 0, 255, 0, MAX_BAR_HEIGHT);
        uint16_t prevHeight = map(prevLevel, 0, 255, 0, MAX_BAR_HEIGHT);
        uint16_t barY = BAR_Y_OFFSET + (MAX_BAR_HEIGHT - currentHeight);
        uint16_t prevBarY = BAR_Y_OFFSET + (MAX_BAR_HEIGHT - prevHeight);
        digitalWrite(TFT_CS_BIG, HIGH);
        if (currentHeight > prevHeight) fillRectSmall(x, barY, barWidth, prevBarY - barY, getGradientColor(currentLevel, i));
        else if (currentHeight < prevHeight) fillRectSmall(x, prevBarY, barWidth, barY - prevBarY, COLOR_BG);
        prevBandLevels[i] = currentLevel;
    }
}
void initSmallScreen() {
    cmdSmall(0x01); delay(150); cmdSmall(0x11); delay(150);
    cmdSmall(0x3A); dataSmall(0x55); cmdSmall(0x36); dataSmall(0x68); cmdSmall(0x29); clearSmall(COLOR_BLACK);
}
void initBigScreen() {
    cmdBig(0x01); delay(150); cmdBig(0x11); delay(150);
    cmdBig(0x3A); dataBig(0x55); cmdBig(0x36); dataBig(0xE8); cmdBig(0x29); clearBig(COLOR_BLACK);
}

// ========================================
//  EXECUTIE MOTOARE (Core 1)
// ========================================
void executeMotors(int8_t drive, int8_t steer, uint8_t speedLvl) {
    int pwmValue = 0;
    if (speedLvl == 0) pwmValue = 2048;      
    else if (speedLvl == 1) pwmValue = 3071; 
    else pwmValue = 4095;                   

    if (drive == 0 && steer == 0) {
        pwm.setPWM(MOTOR1_ENA, 0, 0); pwm.setPWM(MOTOR2_ENB, 0, 0);
        pwm.setPWM(MOTOR1_IN1, 0, 0); pwm.setPWM(MOTOR1_IN2, 0, 0);
        pwm.setPWM(MOTOR2_IN3, 0, 0); pwm.setPWM(MOTOR2_IN4, 0, 0);
        return;
    }

    int leftSpeed = pwmValue;
    int rightSpeed = pwmValue;
    if (steer == -1) leftSpeed = pwmValue / 3; 
    else if (steer == 1) rightSpeed = pwmValue / 3;

    if (drive == 0) { // Rotire
        if (steer == -1) { 
            pwm.setPWM(MOTOR1_IN1, 0, 0); pwm.setPWM(MOTOR1_IN2, 0, 4095); pwm.setPWM(MOTOR1_ENA, 0, pwmValue);
            pwm.setPWM(MOTOR2_IN3, 0, 0); pwm.setPWM(MOTOR2_IN4, 0, 4095); pwm.setPWM(MOTOR2_ENB, 0, pwmValue);
        } else if (steer == 1) {
            pwm.setPWM(MOTOR1_IN1, 0, 4095); pwm.setPWM(MOTOR1_IN2, 0, 0); pwm.setPWM(MOTOR1_ENA, 0, pwmValue);
            pwm.setPWM(MOTOR2_IN3, 0, 4095); pwm.setPWM(MOTOR2_IN4, 0, 0); pwm.setPWM(MOTOR2_ENB, 0, pwmValue);
        }
    }
    else if (drive == 1) { // FATA
        pwm.setPWM(MOTOR1_IN1, 0, 4095); pwm.setPWM(MOTOR1_IN2, 0, 0); pwm.setPWM(MOTOR1_ENA, 0, leftSpeed);
        pwm.setPWM(MOTOR2_IN3, 0, 0); pwm.setPWM(MOTOR2_IN4, 0, 4095); pwm.setPWM(MOTOR2_ENB, 0, rightSpeed);
    }
    else if (drive == -1) { // SPATE
        pwm.setPWM(MOTOR1_IN1, 0, 0); pwm.setPWM(MOTOR1_IN2, 0, 4095); pwm.setPWM(MOTOR1_ENA, 0, leftSpeed);
        pwm.setPWM(MOTOR2_IN3, 0, 4095); pwm.setPWM(MOTOR2_IN4, 0, 0); pwm.setPWM(MOTOR2_ENB, 0, rightSpeed);
    }
}

// ========================================
//  TASK-URI
// ========================================

// TASK MOTOARE (Core 1)
void motorTask(void *pvParameters) {
    MotorPacket mp;
    uint32_t lastCmdTime = millis();
    
    for(;;) {
        if (xQueueReceive(motorQueue, &mp, pdMS_TO_TICKS(20))) {
            lastCmdTime = millis();
            executeMotors(mp.drive, mp.steer, mp.speed);
        } else {
            if (millis() - lastCmdTime > 500) {
                 executeMotors(0, 0, 0);
            }
        }
    }
}

// TASK DISPLAY (Core 1) - Yields more often for motors
void displayTask(void *pvParameters) {
    for (;;) {
        uint8_t requestedFace = incomingDataState.faceIdx;
        if (requestedFace == 0) requestedFace = 4;

        if (currentFace != requestedFace) {
            currentFace = requestedFace; drawFace(currentFace);
        } else {
            digitalWrite(TFT_CS_BIG, HIGH);
        }

        if (millis() - lastRecvTime < 1000 && musicPlaying) {
            updateVisualizerFromAudio(); screenIsBlack = false;
        } else {
            if (!screenIsBlack) {
                clearSmall(COLOR_BLACK); triggerStrobe(false); strobeActive = false;
                for (int i = 0; i < NUM_BANDS; i++) { bandLevels[i] = 0; prevBandLevels[i] = 0; }
                screenIsBlack = true; drawFace(currentFace);
            }
        }
        vTaskDelay(pdMS_TO_TICKS(15)); 
    }
}

// AUDIO TIMER (Core 0) - CALITATE REPARATA
// Am scos filtrul de netezire si am crescut volumul!
void IRAM_ATTR onAudioTimer(void *arg) {
    uint8_t samples[2];
    size_t bytes = xStreamBufferReceiveFromISR(audioBuffer, samples, 2, NULL);
    
    // NU MAI FOLOSIM FILTRUL DE NETEZIRE CARE STRICA CALITATEA
    if (bytes == 2) {
        int16_t rawSample16 = (int16_t)((samples[1] << 8) | samples[0]);
        
        // Atentuare mai mica (90% volum) pentru claritate maxima
        int32_t attenuated = (rawSample16 * 9) / 10;
        
        int16_t outVal = (attenuated / 256) + 128;

        // Fara Low Pass Filter! Direct la DAC.
        if (outVal > 255) outVal = 255; 
        if (outVal < 0) outVal = 0;
        
        dac_oneshot_output_voltage(dac_left, (uint8_t)outVal); 
        dac_oneshot_output_voltage(dac_right, (uint8_t)outVal);
    } else {
        // Daca nu avem date, tinem DAC-ul STABIL la 128 (Mijloc)
        // Nu facem fade-out pentru ca ala cauza zgomotul de "tiuit"
        dac_oneshot_output_voltage(dac_left, 128); 
        dac_oneshot_output_voltage(dac_right, 128);
    }
}

void OnDataRecv(const esp_now_recv_info *recv_info, const uint8_t *incoming, int len) {
    lastRecvTime = millis();
    MotorPacket packet; 
    bool sendMotor = false;

    if (len == sizeof(RemoteState)) {
        memcpy(&incomingDataState, incoming, sizeof(incomingDataState));
        musicPlaying = false;
        if (incomingDataState.currentGenre != activeGenre) activeGenre = incomingDataState.currentGenre;
        
        packet.drive = incomingDataState.dc.drive;
        packet.steer = incomingDataState.dc.steer;
        packet.speed = incomingDataState.speed;
        sendMotor = true;
    } 
    else if (len == sizeof(StreamingPacket)) {
        memcpy(&incomingDataSP, incoming, sizeof(incomingDataSP));
        musicPlaying = true;
        
        packet.drive = incomingDataSP.dc.drive;
        packet.steer = incomingDataSP.dc.steer;
        packet.speed = 2; 
        sendMotor = true;

        long sum = 0; for (int i = 0; i < 240; i += 2) sum += abs((int)incomingDataSP.audioData[i] - 128);
        currentVolume = sum / 120;
        xStreamBufferSendFromISR(audioBuffer, incomingDataSP.audioData, 240, NULL);
    }

    if (sendMotor) {
        xQueueOverwriteFromISR(motorQueue, &packet, NULL);
    }
}

void setup() {
    Serial.begin(115200);

    spi.begin(18, -1, 23, -1);
    spi.setFrequency(2000000); spi.setDataMode(SPI_MODE0); spi.setBitOrder(MSBFIRST);

    pinMode(SR_LATCH, OUTPUT); pinMode(TFT_WR, OUTPUT); pinMode(TFT_RS, OUTPUT); pinMode(TFT_RST, OUTPUT);
    pinMode(TFT_CS_SMALL, OUTPUT); pinMode(TFT_CS_BIG, OUTPUT);

    digitalWrite(TFT_CS_SMALL, HIGH); digitalWrite(TFT_CS_BIG, HIGH);
    digitalWrite(TFT_WR, HIGH); digitalWrite(TFT_RS, HIGH); digitalWrite(SR_LATCH, HIGH);
    digitalWrite(TFT_RST, HIGH); delay(50); digitalWrite(TFT_RST, LOW); delay(50); digitalWrite(TFT_RST, HIGH); delay(200);

    initSmallScreen(); initBigScreen();

    // I2C & Motoare
    Wire.begin(I2C_SDA, I2C_SCL);
    pwm.begin();
    pwm.setPWMFreq(1000); 
    executeMotors(0, 0, 0);

    motorQueue = xQueueCreate(1, sizeof(MotorPacket));

    WiFi.mode(WIFI_STA); esp_wifi_set_max_tx_power(84); esp_wifi_set_ps(WIFI_PS_NONE);
    if (esp_now_init() != ESP_OK) return;
    esp_now_register_recv_cb(OnDataRecv);

    // BUFFER PUTIN MAI MARE PT SIGURANTA
    audioBuffer = xStreamBufferCreate(10240, 1);
    
    dac_oneshot_config_t dac_conf = { .chan_id = DAC_CHAN_0 };
    dac_oneshot_new_channel(&dac_conf, &dac_left); dac_oneshot_output_voltage(dac_left, 128);
    dac_conf.chan_id = DAC_CHAN_1;
    dac_oneshot_new_channel(&dac_conf, &dac_right); dac_oneshot_output_voltage(dac_right, 128);

    const esp_timer_create_args_t timer_args = { .callback = &onAudioTimer, .name = "audio_timer" };
    esp_timer_create(&timer_args, &audio_timer);
    esp_timer_start_periodic(audio_timer, 62);

    // LANSARE TASKS (BALANSARE NUCLEE PT STABILITATE)
    xTaskCreatePinnedToCore(displayTask, "DisplayTask", 4096, NULL, 1, NULL, 1);
    xTaskCreatePinnedToCore(motorTask, "MotorTask", 2048, NULL, 1, NULL, 1);
}

void loop() {
    delay(10);
}

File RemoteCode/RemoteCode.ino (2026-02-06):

#include "globals.h"
#include "inputHandler.h"
#include "displayHandler.h"
#include "commsHandler.h"
#include <esp_now.h>
#include <WiFi.h>

// Shared Global State and Queue
RemoteState myRemote;
DriveCommand myDc;
QueueHandle_t commsQueue;
EventGroupHandle_t commsEvents;
StreamingPacket myStreaming;
SemaphoreHandle_t xTransmitSemaphore;

int batterySamples[5];
int sampleIndex = 0;
unsigned long lastSampleTime = 0;

// --- DEFINIRE VECTOR GENURI (DE LA TINE) ---
uint8_t songGenres[MAX_SONGS]; 

void triggerBeep(int freq, int duration) {
  tone(BUZZER_PIN, freq, duration);
}

// --- TASK 1: UI, Inputs, and Display (CORE 1) ---
void uiTask(void *pvParameters) {
  setupInputs();
  Serial2.begin(NEXTION_BAUD, SERIAL_8N1, RXD2, TXD2);
  digitalWrite(DISPLAY_POWER_PIN, HIGH);

  for (;;) {
    updateInputs(myRemote);
    updateDisplay(myRemote);
    espDeepSleep();
    xQueueOverwrite(commsQueue, &myRemote);
    vTaskDelay(pdMS_TO_TICKS(50));
  }
}

// --- TASK 2: Comms & Battery (CORE 0) ---
void commsTask(void *pvParameters) {
  setupComms();
  esp_now_register_send_cb(OnDataSent);
  uint32_t lastBatteryCheck = 0;

  for (;;) {
    EventBits_t bits = xEventGroupWaitBits(commsEvents, EVENT_SEND_REMOTE_STATE | EVENT_SEND_STREAMING, pdTRUE, pdFALSE, pdMS_TO_TICKS(10));

    if (bits & EVENT_SEND_REMOTE_STATE) {
      esp_now_send(robotAddress, (uint8_t *)&myRemote, sizeof(myRemote));
      Serial.println("Sent: RemoteState");
    }
    if (bits & EVENT_SEND_STREAMING) {
      esp_now_send(robotAddress, (uint8_t *)&myStreaming, sizeof(myStreaming));
      Serial.println("Sent: Audio Packet");
    }
    if (!myRemote.musicPlaying) {
      esp_now_send(robotAddress, (uint8_t *)&myRemote, sizeof(myRemote));
    }

    if (millis() - lastSampleTime > 2000) {  
      batterySamples[sampleIndex] = getBatteryPercentage();
      sampleIndex++;
      lastSampleTime = millis();
      if (sampleIndex >= 5) {
        int sum = 0;
        for (int i = 0; i < 5; i++) sum += batterySamples[i];
        int averagePercentage = sum / 5;
        sendBatteryIconToNextion(averagePercentage);
        sampleIndex = 0;
      }
      vTaskDelay(pdMS_TO_TICKS(10));  
    }
  }
}

void audioSenderTask(void *pvParameters) {
    uint8_t audioBuffer[240];
    const TickType_t xFrequency = pdMS_TO_TICKS(7);
    TickType_t xLastWakeTime;

    for(;;) {
        if (!myRemote.musicPlaying) {
            vTaskDelay(pdMS_TO_TICKS(100));
            continue;
        }
        if (myRemote.trackID >= totalSongs) {
            myRemote.musicPlaying = false; continue;
        }

        char path[70];
        snprintf(path, sizeof(path), "/%s", songList[myRemote.trackID]);
        File audioFile = SD.open(path);
        if (!audioFile) {
            Serial.printf("Error: Could not open %s\n", path);
            myRemote.musicPlaying = false;
            continue;
        }

        audioFile.seek(44);
        Serial.printf("🎵 Playing: %s (Genre ID: %d)\n", path, songGenres[myRemote.trackID]);

        xLastWakeTime = xTaskGetTickCount();
        uint32_t packetCounter = 0; 

        while (audioFile.available() && myRemote.musicPlaying) {
            size_t bytesRead = audioFile.read(audioBuffer, 240);
            memcpy(myStreaming.audioData, audioBuffer, sizeof(audioBuffer));
            myStreaming.dc = myRemote.dc;
            myStreaming.driveControl = false;
            myStreaming.packetId = packetCounter++; 
            
            esp_now_send(robotAddress, (uint8_t *)&myStreaming, sizeof(StreamingPacket));
            
            if (xSemaphoreTake(xTransmitSemaphore, pdMS_TO_TICKS(50)) != pdTRUE) {
                Serial.println("Radio Congestion!");
            }
            vTaskDelayUntil(&xLastWakeTime, xFrequency);
        }
        audioFile.close();
        if (myRemote.musicPlaying) myRemote.musicPlaying = false;
    }
}

void OnDataSent(const wifi_tx_info_t *tx_info, esp_now_send_status_t status) {
  BaseType_t xHigherPriorityTaskWoken = pdFALSE;
  xSemaphoreGiveFromISR(xTransmitSemaphore, &xHigherPriorityTaskWoken);
  if (xHigherPriorityTaskWoken) portYIELD_FROM_ISR();
}

void setup() {
  Serial.begin(BAUD_RATE);
  pinMode(BUZZER_PIN, OUTPUT);
  pinMode(DISPLAY_POWER_PIN, OUTPUT);
  digitalWrite(DISPLAY_POWER_PIN, HIGH);

  myRemote.musicPlaying = false;

  if (!SD.begin(5)) {
    Serial.println("CRITICAL ERROR: SD Card Mount Failed!");
    return;
  }
  Serial.println("SD Mounted Successfully.");
  scanSDCard(); // Apeleaza functia actualizata din inputHandler.h

  commsQueue = xQueueCreate(1, sizeof(RemoteState));
  commsEvents = xEventGroupCreate();
  xTransmitSemaphore = xSemaphoreCreateBinary();
  if (commsQueue != NULL) {
    xTaskCreatePinnedToCore(commsTask, "Comms", 4000, NULL, 2, NULL, 0);
    xTaskCreatePinnedToCore(uiTask, "UI", 4000, NULL, 1, NULL, 1);
    xTaskCreatePinnedToCore(audioSenderTask, "Audio", 4000, NULL, 3, NULL, 0);
  }
}

void loop() { vTaskDelete(NULL); }

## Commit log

2026-02-03 Transmission tests + battery reading adjustments
2026-02-06 fixed song scroll + test modes
    [AntonioCode.ino, RemoteCode.ino, displayHandler.h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]
2026-02-06 fixed song images randomizer
    [displayHandler.h]
2026-02-09 Create Stl Files
